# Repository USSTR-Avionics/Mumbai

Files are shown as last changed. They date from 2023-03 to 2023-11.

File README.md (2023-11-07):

`aamchi mumbai!!!`




# Introduction

Welcome to our hardware-based repository, dedicated to providing innovative designs for modular boards that utilize the CANbus interface. At our repository, we strive to bring the benefits of modularity to hardware design, allowing for greater flexibility, scalability, and customization. Our designs are built using the robust and reliable CANbus interface, ensuring efficient communication and seamless integration between modules. Whether you're a hardware enthusiast, a researcher, or an engineer looking to build custom hardware solutions, our repository has something to offer. Our goal is to create a community of like-minded individuals who are passionate about hardware design, and we invite you to join us on this exciting journey. Browse our collection of designs, collaborate with others, and let's push the boundaries of what's possible with modular hardware.

PDB and GPS copied over from: https://github.com/USSTR-Avionics/PDB and https://github.com/USSTR-Avionics/gps-board

RF board based on OpenLST: https://github.com/OpenLST/openlst-hw

## Standard and Unified Connector Kit
Pinout  
10x2 connector

|  | 1 | 2 | 3 | 4 | 5 | 6 | 7 | 8 | 9 | 10 |
|---|---|---|---|---|---|---|---|---|---|---|
| **A** | GND | 3V3 |GND | 3V3 | GND | 5V | GND | 5V | GND | Bus voltage | 
| **B** | GND | CAN high | CAN low | GND | GPIO | GPIO | GPIO | GPIO | GPIO  | GPIO  

(left to right, topview)

[hard to flip header](https://www.digikey.ca/en/products/detail/sullins-connector-solutions/SFH11-PBPC-D10-ST-BK/1990090)

## PCB Dimensions Drawing
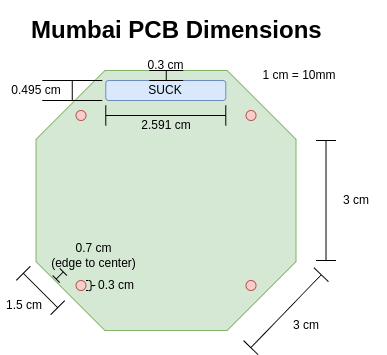
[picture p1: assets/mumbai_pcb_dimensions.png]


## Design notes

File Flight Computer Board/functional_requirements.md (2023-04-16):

# Purposes and Scope

The flight computer should be a general purpose flight computer that allows us to have high performance, modularity,
encapsulation and object oriented design. Provide unparalledled situational awarenedd using edge functions on the
lambda cloud. All instructions and code are encrypted using null key encryption and single source of truth blockchain
technologies to avoid tampering with the data.

# Functional Requirements

## Materials
- microcontroller
    - STM32F205RBT6 
    - debug/ program pins

- attitude sensors
    - accelerometer
    - gyroscope
    - magnetometer
    - barometer

- IO peripherals
    - multi-colour LED arrays
    - buzzer
    - FRAM

- communication
    - CAN transceiver

# Non-functional Requirements

- sensor redundancy
    - accelerometer
    - gyroscope
    - magnetometer
    - barometer

# Assumptions and Dependencies

All of it will work

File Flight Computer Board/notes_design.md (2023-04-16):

- NRST pulled low, reset the uc, contains internal pullup resistor
    - maybe attach an external switch

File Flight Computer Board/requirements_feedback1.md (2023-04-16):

# Materials
- microcontroller
* WHAT MICROCONTROLLER, STM32***, will be decided by Dylan
- MS5611
** REASEARCH DIFFERENT BAROMETERS AND GIVE ME AN ANALYSIS ON WHAT ONE IS BEST, HOW MANY FOR REDUNDANCY
- KX134
** REASEARCH DIFFERENT ACCELEROMETERS AND GIVE ME AN ANALYSIS ON WHAT ONE IS BEST, HOW MANY FOR REDUNDANCY
- BMP280
- MPU6050
** DIFFERENT IMU, AN IMU HAS AN ACCELEROMETER IN IT, 9 AXIS WOULD BE NICE 6 is OK
- indicator LEDs
*SURFACE MOUNT
- buzzer
* GIVE ME A USABLE BUZZER, IT JUST HAS TO WORK
- CAN transceiver
* WILL BE STANDARDIZED BY DYLAN
THE FLIGHT COMPUTER SHALL DO THIS **MUST
THE FLIGHT COMPUTER SHOULD DO THIS *NICE TO HAVE
# Functionality
- get serial monitor output
- transmit and receive CAN messages from all boards on CAN BUS
- GPIO pins for extensibilty (CONNECTORS????!!!!)
- Be programmable from the outside of the rocket, easily accessible
- Shall be able to convert analog sensor values to digital values (instrumention, current/voltage)

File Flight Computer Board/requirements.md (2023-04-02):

# Materials

- microcontroller
- MS5611
- KX134
- BMP280
- MPU6050
- indicator LEDs
- buzzer
- CAN transceiver

# Functionality

- ability to program the microcontroller
- get serial monitor output
- transmit and receive CAN messages
- GPIO pins for extensibilty

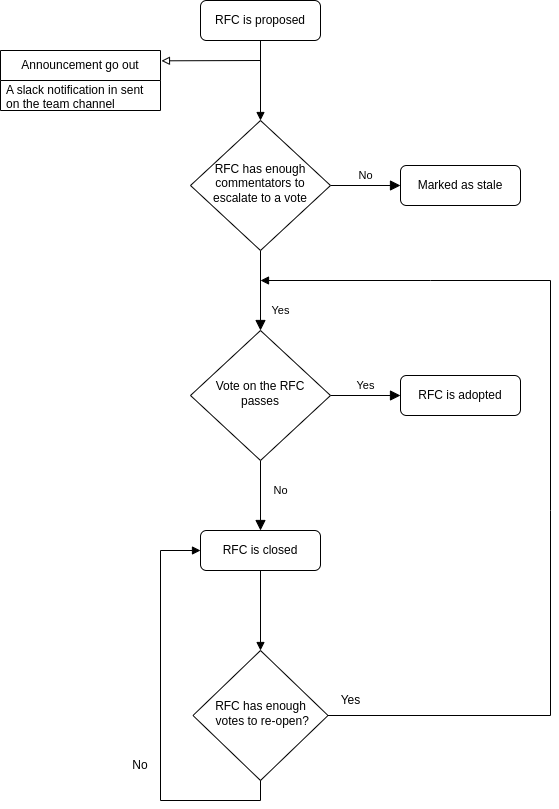
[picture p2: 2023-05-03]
assets/rfc_process_diagram.png

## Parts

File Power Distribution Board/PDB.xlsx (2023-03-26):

Reference | Quantity | Value | Footprint | LCSC Part #
C101 C102 C107 C108 C109 | 5 | 0.1uF | Capacitor_SMD:C_0805_2012Metric_Pad1.18x1.45mm_HandSolder
C103 C104 | 2 | 10uF | Capacitor_SMD:C_0805_2012Metric_Pad1.18x1.45mm_HandSolder
C105 C106 | 2 | 22uF | Capacitor_SMD:C_0805_2012Metric_Pad1.18x1.45mm_HandSolder
C110 | 1 | 4u7 | Capacitor_SMD:C_0805_2012Metric_Pad1.18x1.45mm_HandSolder | C19666
C111 C113 | 2 | 30p | Capacitor_SMD:C_0805_2012Metric_Pad1.18x1.45mm_HandSolder | C1570
C112 C114 C116 C117 C118 | 5 | 100n | Capacitor_SMD:C_0805_2012Metric_Pad1.18x1.45mm_HandSolder | C1525
C115 | 1 | 1u | Capacitor_SMD:C_0805_2012Metric_Pad1.18x1.45mm_HandSolder | C52923
D101 | 1 | SB140 | Diode_THT:D_DO-41_SOD81_P10.16mm_Horizontal
D102 D103 D104 | 3 | LED | LED_SMD:LED_0805_2012Metric_Pad1.15x1.40mm_HandSolder
J101 | 1 | Conn_01x02_Female | Connector_AMASS:AMASS_XT60PW-F_1x02_P7.20mm_Horizontal
J102 | 1 | Conn_01x08_Female | Connector_PinHeader_1.27mm:PinHeader_1x08_P1.27mm_Horizontal
J104 | 1 | Conn_01x06_Female | Connector:Tag-Connect_TC2030-IDC-FP_2x03_P1.27mm_Vertical
JP101 | 1 | SolderJumper_2_Open | Jumper:SolderJumper-2_P1.3mm_Open_Pad1.0x1.5mm
L101 | 1 | 27n | Inductor_SMD:L_0402_1005Metric | C18830
R101 | 1 | 120 | Resistor_SMD:R_0805_2012Metric_Pad1.20x1.40mm_HandSolder
R102 | 1 | 200mR | Resistor_SMD:R_0805_2012Metric_Pad1.20x1.40mm_HandSolder
R103 R104 R105 | 3 | 1k | Resistor_SMD:R_0805_2012Metric_Pad1.20x1.40mm_HandSolder
R106 | 1 | 10k | Resistor_SMD:R_1206_3216Metric_Pad1.30x1.75mm_HandSolder
R107 | 1 | 2k | Resistor_SMD:R_1206_3216Metric_Pad1.30x1.75mm_HandSolder
R108 | 1 | 10k | Resistor_SMD:R_0805_2012Metric_Pad1.20x1.40mm_HandSolder | C25744
U101 | 1 | AZ1084-3.3 | Package_TO_SOT_SMD:TO-252-2
U102 | 1 | MCP2562-H-SN | Package_SO:SOIC-8_3.9x4.9mm_P1.27mm
U103 | 1 | AZ1117-5.0 | Package_TO_SOT_SMD:TO-252-3_TabPin2
U104 | 1 | INA180 | Package_TO_SOT_SMD:SOT-23-5_HandSoldering
U105 | 1 | STM32F103C8T6 | Package_QFP:LQFP-48_7x7mm_P0.5mm | C8734
Y101 | 1 | 8MHz | Crystal:Crystal_SMD_5032-2Pin_5.0x3.2mm | C115962

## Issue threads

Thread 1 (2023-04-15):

Radio Board revA Hardware schematic RFC

ATGr8, 2023-04-15:
Need two Passes to move onto layout as discussed in the design review.
Design files: https://github.com/USSTR-Avionics/Mumbai/tree/master/RF
Let me know if you have further questions

tyrelkostyk, 2023-04-16:
Approved.

Since the majority of these changes are utilizing a somewhat proven open source design, there's not too much to comment on. Be sure to thoroughly test the added components (external memory), and consider investigating what other people have done when making modifications to the firmware/hardware for this design. There will definitely be some trial-and-error when using that external memory, but it shouldn't be too hard. Let me know if you experience significant issues and I can try and lend a hand.

Colton-Breitkreuz, 2023-04-18:
Approved.

Closed 2023-04-18.

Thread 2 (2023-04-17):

RFC 202304162103 - Standardising and Unifying Connector Kits (SUCK)

frroossst, 2023-04-17:
How do our boards communicate with each other and what does the connector looks like

frroossst, 2023-04-17:
So, in essence the SUCK or the Standard Unified Connector Kit would have
5V
3V3
GND
4x CAN wires(no clue how many wires CAN takes)
GPIOS (number to be specified)

ATGr8, 2023-04-17:
Dont need 4 CAN wires, just two wires: CANH and CANL, so just 2

AstroJosh2002, 2023-04-17:
have a common connector for all boards and only connect what you need on each board

frroossst, 2023-04-17:
We might need a separate bus to not bog down the main CANbus line for things like, images from a camera, or something that takes up a lot of bandwidth

dhaussecker, 2023-04-17:
Why can't you use CAN for everything? Connect sensors to a MCU and that MCU goes to CAN BUS

dhaussecker, 2023-04-17:
What type of sensors would connect to these GPIOs? Are these flight critical sensors?

ATGr8, 2023-04-17:
We don't know yet, but we need the flexibility to add non complex boards that can just plug into the GPIOs, adding a MCU for such boards is overkill and add more points of failure.

dhaussecker, 2023-04-17:
Each board will have standard GPIOs so if a sensor needs to be added to the rocket in a certain location in the future, it can be easily done. It is a transportation system between all boards (priority based) using CAN to easily replace and add more sensors

frroossst, 2023-04-17:
finally!!!!

frroossst, 2023-04-17:
PC104 ftw

dhaussecker, 2023-04-17:
All Boards IN THE STACK can use PC104 Connectors, as long as they will meet launch Canada Requirements

dhaussecker, 2023-04-17:
Boards in other sections of the rocket will need something else, determined later

frroossst, 2023-04-17:
you can't just comment things here that we tell you on discord!

dhaussecker, 2023-04-17:
ALL STANDARDS ARE SUBJECT TO DESIGN CHANGES IF DEEMED NECESSARY IN THE FUTURE

AstroJosh2002, 2023-04-17:
I approve the current design

frroossst, 2023-04-17:
approve deez nuts

frroossst, 2023-04-17:
CENSORSHIP!

AstroJosh2002, 2023-04-17:
I can't believe we spent more than 30 mins convincing Dylan why GPIO is a good idea

frroossst, 2023-04-17:
# Pinout
(left to right)

| GND | 3V3 |GND | 3V3 | GND | 5V | GND | 5V | GND | Bus voltage |
|---|---|---|---|---|---|---|---|---|---|
| GND | CAN hi | CAN lo | GND | GPIO | GPIO | GPIO | GPIO | GPIO  | GPIO

10x2 connector

AstroJosh2002, 2023-04-17:
https://www.digikey.com/en/products/detail/samtec-inc/ESQ-105-23-S-D/7090235

ATGr8, 2023-04-17:
https://www.digikey.ca/en/products/detail/sullins-connector-solutions/SFH11-PBPC-D10-ST-BK/1990090
I like this one cause it has a indication of first row so we cant flip it

AstroJosh2002, 2023-04-17:
https://www.mouser.ca/c/connectors/backplane-connectors/pc-104-connectors/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

ATGr8, 2023-04-17:
https://www.digikey.ca/en/products/filter/rectangular-connectors/headers-receptacles-female-sockets/315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
Digikey filter for us

AstroJosh2002, 2023-04-17:
Header dimentions https://suddendocs.samtec.com/prints/esq-1xx-xx-x-x-xxx-xx-x-xx-mkt.pdf

AstroJosh2002, 2023-04-17:
https://www.mouser.ca/ProductDetail/Samtec/ESQ-110-38-G-D?qs=0lQeLiL1qya%252BPHAV3ltgtA%3D%3D

AstroJosh2002, 2023-04-17:
Probably the best one https://www.mouser.ca/ProductDetail/Samtec/ESQ-110-13-G-D?qs=0lQeLiL1qyaTGIi6Og3PNg%3D%3D

Closed 2023-04-17.

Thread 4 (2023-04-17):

Preliminary selection of micro-controllers for the hardware

frroossst, 2023-04-17:
## Micro-controllers
| Micro-controller | Price |Stock | Core | Max Clock (MHz) | Program Memory Size (MB) | Number of IOs | CAN | I2C | SPI | UART | USART | USB |
|:-----|:-----:|:--:|:----------:|:----:|:----------------:|:--------------------:|:--------:|:----:|:----:|:----:|:----:|:--:|
|STM32F405RGT6 |20.04|0| M4 |168|1|51|1|1|1|1|1|1|
|STM32F407IGT6 |25.71|0|M4|168|1|140|1|1|1|1|1|1|
|STM32F412VGT6|20.2|2143|M4|100|1|81|0|0|0|0|0|0|
|STM32F413VGT6 |19.53|941|M4|100|1|81|1|1|1|1|1|1|
|STM32G0B1VET6|13.85|1064|M0+|64|0.5|94|1|1|1|1|1|0|
|STM32G0C1RET6|12.16|604|M0+|64|0.5|60|1|1|1|1|1|1|
|STM32L4R9VGT6 |25.6|879|M4|120|1|77|1|1|1|1|1|1|
|STM32F412RGT6|19.17|1910|M4|100|1|50|1|1|1|1|1|1|
|STM32L476RET6|18.02|18349|M4|80|0.5|51|1|1|1|1|1|1|
|STM32L462RET6|16.28|3830|M4|80|0.5|52|1|1|1|1|1|1|
|STM32L451RET6TR|15.17|6980|M4|80|0.5|52|1|1|1|1|1|1|

## Footer
> 1 means, it supports that, 0 means it doesn't rather than the actual quantity

frroossst, 2023-04-17:
@dhaussecker need your attention!

dhaussecker, 2023-04-17:
Consider Platform-IO capability, and list what supplier you are getting information on the stock. Option 1 looks the best to me based on this at the moment (but the supply chain crisis might be difficult to navigate, there is stock from other suppliers but IDK where you got your stock information from), also considering availability from JLCPCB parts for potential of quick board manufacturing

STM32F405RGT6 | 20.04 | 0 | M4 | 168 | 1 | 51 | 1 | 1 | 1 | 1 | 1 | 1 | PIO | JLC $7.98 (1075 stock)
STM32F407IGT6 | 25.71 | 0 | M4 | 168 | 1 | 140 | 1 | 1 | 1 | 1 | 1 | 1 | PIO JLC  $48.2687 (581 stock)
STM32F412VGT6 | 20.2 | 2143 | M4 | 100 | 1 | 81 | 0 | 0 | 0 | 0 | 0 | 0 |
STM32F413VGT6 | 19.53 | 941 | M4 | 100 | 1 | 81 | 1 | 1 | 1 | 1 | 1 | 1 |
STM32G0B1VET6 | 13.85 | 1064 | M0+ | 64 | 0.5 | 94 | 1 | 1 | 1 | 1 | 1 | 0 | NOPIO
STM32G0C1RET6 | 12.16 | 604 | M0+ | 64 | 0.5 | 60 | 1 | 1 | 1 | 1 | 1 | 1
STM32L4R9VGT6 | 25.6 | 879 | M4 | 120 | 1 | 77 | 1 | 1 | 1 | 1 | 1 | 1
STM32F412RGT6 | 19.17 | 1910 | M4 | 100 | 1 | 50 | 1 | 1 | 1 | 1 | 1 | 1 | PIO JLC 13.8318 (86 stock)
STM32L476RET6 | 18.02 | 18349 | M4 | 80 | 0.5 | 51 | 1 | 1 | 1 | 1 | 1 | 1
STM32L462RET6 | 16.28 | 3830 | M4 | 80 | 0.5 | 52 | 1 | 1 | 1 | 1 | 1 | 1
STM32L451RET6TR | 15.17 | 6980 | M4 | 80 | 0.5 | 52 | 1 | 1 | 1 | 1 | 1 | 1

frroossst, 2023-04-17:
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

Stock information is from mouser.ca and digikey.ca. (mostly mouser)

Also, not to be THAT guy, but PlatformIO compatibility just needs to be thrown down the drain, at least from my perspective (writing firmware) I won't be able to use pio, I have to use the STM_IDE. Most of these are however compatible with pio. But we wouldn't know until we try it out. In essence, if the CPU and architecture are supported, so should a specific board be.

ATGr8, 2023-04-18:
I second not worrying about PIO compatibility, STMCube IDE gives access to a lot more natively

ATGr8, 2023-04-18:
Another thing to consider would be the package, you don't wanna get QFN or BGAs because those would be painful to solder

frroossst, 2023-04-18:
I mainly went with a LQM package

ATGr8, 2023-04-18:
As long as the pins aren't _under_ the chip its fine.

For the UART and USART: are they on different pins or is the UART able to add a clock to make USART?

dhaussecker, 2023-04-18:
Only 3 microcontrollers have platform io capability from what I can tell. It was a group decision 2 weeks ago in the avionics meeting that the people programming the software want the capability to program these microcontrollers using platform io as it takes considerably less time to program it there. PIO will still be taken into consideration

frroossst, 2023-04-18:
Right, but the team that decided things 2 weeks ago, is not programming the firmware. Also, it is simply impractical to do it with PlatformIO

Also to answer Atharva's question.
> The STM32L4Rxxx devices have three embedded universal synchronous receiver
transmitters (USART1, USART2 and USART3) and two universal asynchronous receiver
transmitters (UART4, UART5)
I think you just attach an external clock

ATGr8, 2023-04-18:
Has the team tried out STM Cube IDE? I don't think taking PIO compatibility as a primary reason for making this decision is a good idea, I wouldn't sacrifice performance for PIO compatibility. However if two have same performance and once supports PIO, we should choose the one with PIO compatibility

frroossst, 2023-04-18:
PIO is 100% better than Arduino, and I hate, HATE, H A T E using proprietary IDEs, but the STM IDE is just far superior for the STM platform. We should choose a micro-controller and then figure our pio, cause regardless it will still work with STM IDE

frroossst, 2023-04-18:
On the topic of the micro-controller, I am leaning towards this [one](https://www.mouser.ca/ProductDetail/STMicroelectronics/STM32L4R9VGT6?qs=wd5RIQLrsJi9fM%2FlO6Dzzw%3D%3D)

Although I would like one with multiple CAN transceivers

ATGr8, 2023-04-18:
@dhaussecker @frroossst
I think it would be a fair sacrifice as considering PIO compatibility as a secondary reason to choose the MCU.

Afterall no one on the team is writing the firmware because there is no STM firmware to write. PIO compatibility would be a nice to have  and would lower the barrier to entry.

ATGr8, 2023-04-18:
> On the topic of the micro-controller, I am leaning towards this [one](https://www.mouser.ca/ProductDetail/STMicroelectronics/STM32L4R9VGT6?qs=wd5RIQLrsJi9fM%2FlO6Dzzw%3D%3D)

Although I would like one with multiple CAN transceivers
It looks like 25 bucks a pop, don't think that's very economical

dhaussecker, 2023-04-18:
I don't think that one is the best decision at all

frroossst, 2023-04-18:
I also love this [one](https://www.mouser.ca/ProductDetail/STMicroelectronics/STM32F205RBT6?qs=ZjM2s42DDyaIgcG0HgMB8w%3D%3D) but, it's on order.

dhaussecker, 2023-04-18:
PIO capability will be a main priority as it reduces the gap of knowledge needed for members to begin programming. Also, makes things way simpler to program. I don't know if either of you have tried programming an STM32 with PIO but I have, it is simple cause you can just import the Arduino library and utilize all extensive libraries that are in that ecosystem. STM32 Cube IDE programming is a secondary objective IMO

ATGr8, 2023-04-18:
Have you tried programming the STM32 Cube IDE? To wirte low level firmware?

ATGr8, 2023-04-18:
Things like assigning pin functions, setting registers is very easy in the Cube IDE cause its all natively built for a particular chip. Doing the same thing on PIO wont work as well and will be difficult. Plus why are we importing Arduino libraries here to write the drivers/firmware?

dhaussecker, 2023-04-18:
But we don't need to be writing low level firmware for this in the first place?! Make things as simple as they can  be

ATGr8, 2023-04-18:
Yes we do. Our boards require us to write low level firmware. Our boards will be bare metal.

frroossst, 2023-04-18:
ummm.....

dhaussecker, 2023-04-18:
They do not have to be bare metal, we will be wasting time writing software when we could be doing other things if we had all the libraries that are provided with PlatformIO-compatible STM32s through the Arduino ecosystem. We will have a lot of tasks to do this year and teaching new first years how to program low level firmware in STM32 IDE is not feasible IMO, especially when we struggled getting everyone to code in PlatformIO at times during this year. For more experienced programmers, sure! Why not use STM32 CubeIDE? It gives you a lot more experience writing low level firmware. But we also need to keep the option for new students who don't know anything about programming, to reduce the learning gap and to keep things as simple as possible.

frroossst, 2023-04-18:
a. If we're not doing bare metal, what are we doing?
b. We will be using the STM32 IDE regardless, as it provided a HAL, pinout and much more. so it's useful for design purposes
c. The first years will not write firmware, by firmware we mean, can bus drivers and stuff. You do not want to mess with dependencies when doing embedded stuff, or heck even C/C++ stuff as they have no good dependency managers
d. We cannot use the two platforms (no pun intended) interchangeably because they operate on different linker scripts
e. If we wanna reduce the learning gap, that the whole stm32 thing might be a bad idea, as they are fundamentally more advanced when compared to something like a Teensy or an Arduino-alternative

ATGr8, 2023-04-18:
I see your point here, but STM 32 Cube is not a steep learning curve and you don't have to write low level firmware in STM32Cube, it could be as high level as PIO.
STM32Cube has more libraries supporting STM32 than PIO, it has the abilities to detect hardware faults.
I'm not against using PIO, but I don't think its justified to use its compatibility as one of the main deciding factors.
Members can also just use VSCode and only click build on Cube IDE if needed, we could also figure out a way to integrate those two.

frroossst, 2023-04-18:
Not to mention, with STM32 you can have hardware breakpoints for days!

dhaussecker, 2023-04-18:
The team as a whole decided that platformIO is the best way to go for now, without formal agreement that STM32 CubeIDE is best in the future I need the majority of the people who will be doing software to agree. In order to determine the feasibility of platformio over stm32 or vice versa we need to do some more programming in both first and make a convincing argument that one is better and convince the majority to accept the argument. Until then I am putting a restriction that the microcontroller needs to be able to be programmed using PlatformIO. @frroossst  had the same concern when I wanted to switch to STM32CubeIDE previously and I followed that suggestion as that is what the team decided. So convince the entire team first who will ultimately end up programming this as well, if you do, I'm good with it. In the meantime, it shouldn't be that difficult to select one that meets all your requirements, the STM32F405RGT6 is $7.98 and is available from LCSC electronics

frroossst, 2023-04-18:
Technically, majority of the people who do software is me. I have more commits on MiniRocket repo than everyone combined (including an effin' linting bot), and since they are commits, Dylan can't make an argument that I just copy pasted the entire code base, cause that's not how commits work. So, I agree we should use STM, therefore, your entire software team is in agreement.

No offense ofc.

frroossst, 2023-04-18:
Also, we don't need to get the whole team's approval on everything. Direct democracy is a very bad thing for an engineering project, We need someone to make decisions that might be unpopular, I am not saying disregard the team, cause I am part of the team lol, but this RFC is a way of getting the team's feedback. If you keep this open for a week or two and no team members are active on here, and then by de facto they have lost the privilege to have their say. So, keep this open for 2 week(s) or so, but, if there are no oppositions here then the decision is made.

dhaussecker, 2023-04-18:
Dylan, Atharva, and Adhyan decided STM32F405RGT6 was the final decision

Closed 2023-04-19.

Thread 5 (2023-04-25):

RFC 202304242108: We do *not* need a memory board

frroossst, 2023-04-25:
- adding a memory board or data logger can create unnecessary redundancy and add complexity to the system.
-  it would need to be programmed to collect data from the other boards, which can create a risk of data loss or communication errors.
- the added weight and size of the memory board or data logger can affect the overall performance of the rocket and potentially impact the flight trajectory.
- centralised board introduces a single point of failure
- If each board logs its own data, it can be done at a higher frequency or a different tick rate than a centralized memory logger. This can provide more accurate and detailed information about the performance of each component, which can be useful for troubleshooting and analysis.
- With each board logging its own data, it can be easier to identify which specific component or subsystem caused any issues during flight. This can help to pinpoint problems and make improvements for future launches.
- With each board logging its own data, it can be easier to identify and isolate any faults or issues that occur during flight. This can help to improve fault tolerance and make the rocket more resilient to future failures.
- With each board logging its own data, the data can be easily transferred to a computer for analysis without the need for a centralized memory logger. This can simplify the data transfer process and reduce the risk of data loss or corruption during transfer.
- Each board can be programmed to log specific data points that are relevant to its function, rather than having to log all data on a centralized logger. This can help to optimize the use of storage space and improve the accuracy of the data collected.
- With each board logging its own data, it can be possible to perform real-time data analysis during flight. This can allow for immediate adjustments to be made if any issues are detected, improving the overall performance and safety of the rocket.
- If each board logs its own data, it can be easier to swap out individual components or subsystems without affecting the data collection process. This can help to improve the modularity of the rocket and make it easier to upgrade or repair.

> Disclaimer: This post is not associated with the Rust Foundation :tm: and powered by chatGPT

<!-- probot = {"36936151":{"who":"frroossst","what":"about RFC vote","when":"2023-05-02T09:00:00.000Z"}} -->

ATGr8, 2023-04-25:
I agree, we do not need a data logger board, it adds complexity that is not necessary and we can just log data from the board the data is coming from in the first place

AstroJosh2002, 2023-04-25:
I'm also in agreement that having more points of failure in the system will cause more problems not only in flight but also during testing. If you have the option to put storage space on the flight computer, why have a seperate board for logging the data to when you can put a larger amount of storage space on your flight computer. Also having more information flowing on the CAN Bus lines has the risk of slowing it down, this can be dangerous when the flight computer needs to make timely decisions and if that's delayed it can put people's safety at risk

frroossst, 2023-04-25:
Here are a few ways we can store data if using a central data logger, the important assumption being data comes in at different tick rates.

1. Have a different chip for every different data type
    - Inefficient to scale
    - Cannot easily change the schema

2. Attach a tagging field
    - Wasting space (would need at least two more bytes, one for the data type being stored and one for how many bytes follow that

3. Hashing
    - Impossible to create a hash function that would have zero collisions

4. Serialising a data chunk
    - Would waste space if a data element is ticked in extremely fast

5. Round Robin Circular Buffer data chunk serialisation
    - Probably the best solution
    - Very space efficient (stores the same amount as the actual data being stored)
    - Difficult to implement, still would waste some space overall

---
This however still does not solve my further hesitation, if any given board does not have any onboard memory chips to store data then while debugging I'll always need to have two boards connected over CAN when debugging, if any given board does indeed have some memory chips on board for quick storage and access then why not increase that storage space and eliminate the memory board altogether?

frroossst, 2023-04-28:
/remind 4 days

frroossst, 2023-04-28:
/remind me about RFC vote in 4 days

dhaussecker, 2023-04-30:
As discussed previously, you are free to implement data logging functionality on the flight computer. we are implementing a data logger board right now for the case that you fail in successfully implementing it on the flight computer which I have deemed it has a high risk at this point with all the other priorities of this board, and time for programming. Prove me wrong 😉 I think a data logger board  would be the perfect “black box” of the system just like airplanes have used for the purposes of redundancy.

frroossst, 2023-05-01:
Again, the central problem with a data logger is an implementation scheme that is memory efficient with all that data coming in at different rates in a non-specific order.

If your data logger fails then you loose 100% of the data, it adds one more board, one more microcontroller to program, one more point of failure. If data logging is handled by each board then we can in theory loose multiple boards while still being able to salvage back some data. A centralised data-logger adds one more layer of complexity.

As @ATGr8 pointed out before, it needs to be a closed loop system, if your data logger shits the bed, then the flight computer cannot get back data.

Also, why would we fail to implement a datalogger on the flight computer? We literally did it on the MiniRocket.

Sidenote: there is no point of an RFC system, if decisions are made unilaterally,

dhaussecker, 2023-05-01:
I believe you are confusing points of failure with redundancies. This is a redundancy which launch Canada wants for all essential systems. I agree with having a chip on every board for the purpose of redundancy

frroossst, 2023-05-01:
Show me where Launch Canada says, we need to have redundancy for data logging

Ukrainianvengeance, 2023-05-02:
How would the control system get all of the flight data? and would we need separate ground stations for each PCB?

frroossst, 2023-05-02:
What do you mean by control system? The flight computer? or the Ground Station?

If you are talking about the flight computer then CANbus? if the ground station then just CANbus and then the radio board handles it?

Can you elaborate a little more on your question?

Ukrainianvengeance, 2023-05-02:
I think I misunderstood yesterday, the data logger would just store the data not process and use the data for flight, right?

frroossst, 2023-05-02:
Yes, it would just be storing the data. Do you have any concerns or questions about it?

Ukrainianvengeance, 2023-05-02:
I no longer have concerns about it and agree with your conclusion as to not needing a central data logger

bristine02, 2023-05-02:
One of our most important goals is modularity and I think having a centralized data logger would make it a little more difficult and messy to add new boards to our system. I think  having each board do its own data collection will help a lot in making our boards modular. It'll also be a lot simpler to test and debug. Also if we decided to swap a board or change stuff on it, we won't need to also make changes to a data logger ( which might affect other boards).

frroossst, 2023-05-03:
Eligible voters: @ATGr8 @AstroJosh2002 @bristine02 @dhaussecker @frroossst @Ukrainianvengeance

:+1: if you are **in support** of the RFC, i.e. there **shouldn't** be a centralised memory logger on board
:-1: if you are **in opposition** of the RFC i.e. there **should** be a centralised memory logger on board

_votes are closed, when all the eligible voters have voted or it is midnight!_

frroossst, 2023-05-03:
This RFC officially passes, with 6 votes in favour and 0 against.

For the time being we will not have a separate memory board on the rocket, this RFC **cannot be reopened**, if a discussion needs to be had on an adjacent topic, mention this RFC, but you have to open a new RFC.

Thank you all for participating!

Closed 2023-05-03.

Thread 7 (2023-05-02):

RFC 202305020937: Impl continuous fuzzing

frroossst, 2023-05-02:
# Abstract
Fuzz testing find bugs, faster, better, and with less effort than writing regular tests, allowing us to focus more of our time on writing code, architecture rather than correctness of the code. This was an active RFC on `USSTR-Avionics/MiniRocket`  but it was too late in its life cycle to do this. Ideally, this would be handled by a github action automatically to find and report bugs. Or it can live on the Esterhazy server.

# Problem(s)
Program robustness, memory safety, correctness, undefined behaviour.

# Solution
Use clang's libfuzz, or write our own fuzz library

# Difficulties and Risks
Even after months of looking into it, I still have very little idea on how to write my own fuzzer.

# Estimated costs and timelines
Should write our own fuzzer in about a month or so, with all the features we want, or impl a fuzzer in a week or so. Saves a lot of cost in the long term.

# Proof of concept
Haven't implemented one yet

# References
https://owasp.org/www-community/Fuzzing
https://releases.llvm.org/9.0.0/docs/LibFuzzer.html
https://www.code-intelligence.com/blog/secure-coding-cpp-using-fuzzing
https://github.com/google/honggfuzz
https://github.com/CodeIntelligenceTesting/cifuzz

<!-- probot = {"36936151":{"who":"fuzz","what":"test RFC","when":"2023-05-16T09:00:00.000Z"}} -->

frroossst, 2023-05-02:
This is a complex topic that requires in depth discussions, so I will leave this open for two weeks.

/remind fuzz test RFC in 2 weeks

dhaussecker, 2023-05-03:
Prime example of: “Research done on student rocket projects shows that time and time again, students tend to overcomplicate certain aspects, rather than focusing on the simplest solution that can be effective.”

This is a clear example of this in my opinion, please focus on the simple stuff of implementing all the boards we already have planned and the software for those as that is the simplest thing we can do at this point

dhaussecker, 2023-05-03:
Just because it sounds cool doesn’t mean it is something we need at this point. Reminder: 4 month timeline for all boards and code to be done. Best case scenario this would get done in 2 months,

frroossst, 2023-05-03:
- What research? Source?
- The reasoning is mentioned in the RFC, nowhere is the word "cool" mentioned
- What is your basis for arriving at the conclusion that implementing continuous fuzzing would take 2 months? I LITERALLY linked a reference to a fuzzing library for C++, that you can use right  now
- This in the long term ensures more robust and secure embedded code is written, it **might be** worthwhile to at least have a discussion on it to prevent bugs like the FRAM bug we had!

dhaussecker, 2023-05-03:
- Multiple papers from student project cit this as the most significant issue faced in student projects. For example: https://www.hyrumwright.org/papers/avionics.pdf
- The goal with everything we are doing is asking one simple question: is it absolutely essential for a rocket? Meaning it helps us meet one of the 3 requirements required for avionics (command, control, data acquisition). Remember timelines are quick, we only have a few hours a week committed at this point, any time we can get to make sure our rocket simply works is time we need
- “Should write our own fuzzer in about a month or so”, multiply that timeline by 2 since it will ALWAYS take longer than you think and you get 2 months. If it takes a couple of hours for you to implement an already made library, and develop some documentation on how it works/ how to use it / why is it useful, then I’m for it. But I need to see a valid justification that it will only take a few hours
- if you write good code, get it reviewed properly, and test it,  you shouldn’t have bugs

frroossst, 2023-05-03:
- I haven't dived into the paper yet, but I'll take your word for it now
- It helps the rocket be safe? Since, there is no RTOS, a bug or crash is catastrophic as your engine task stops being executed? What happens on a seg fault? What happens if enough memory can't be allocated? What happens when static variables are mutated improperly? All these operations are inherently even more so an an embedded system
- We should write our own fuzzer eventually, but the goal should be to implement fuzzing in the first place, the crux of the RFC is fuzzing not, implementation of fuzzing. I'm open to any fuzzing lib as long as it serves its purpose and fulfills our needs

ATGr8, 2023-05-05:
Is there a fuzzer that already exists that we can just use?
I like this idea but I don't wanna take away too much time from writing Mumbai software/firmware, could still be convinced that writing our own fuzzer is better for long term but I don't understand it enough to appreciate it.

frroossst, 2023-05-05:
[A gentle introduction to fuzzing C++ code](https://jefftrull.github.io/c++/clang/llvm/fuzzing/sanitizer/2015/11/27/fuzzing-with-sanitizers.html)

I have been saying this for a long time, "If you are smart enough to write tests that catch all the bugs that might arise, aren't you smart enough to write code, without those bugs?" that's why Test Driven Development doesn't work unless you are building something hyper-testable most likely a CLI utililty or a parser.

Writing system tests for a system means emulating the environment around it, which is ridiculously difficult. So, fuzzing just means, you are rawdogging you functions with inputs of all kinds such that you find the bug easily. This is what I've been calling "chaotic testing" for a long time,, just write code, and test it as a full system, something crashes go back and fix.

At work, we've found some very nasty RegEx bugs by just fuzzing. But we all know you should never use RegEx, so that's our bad I guess haha

Closed 2023-05-20.

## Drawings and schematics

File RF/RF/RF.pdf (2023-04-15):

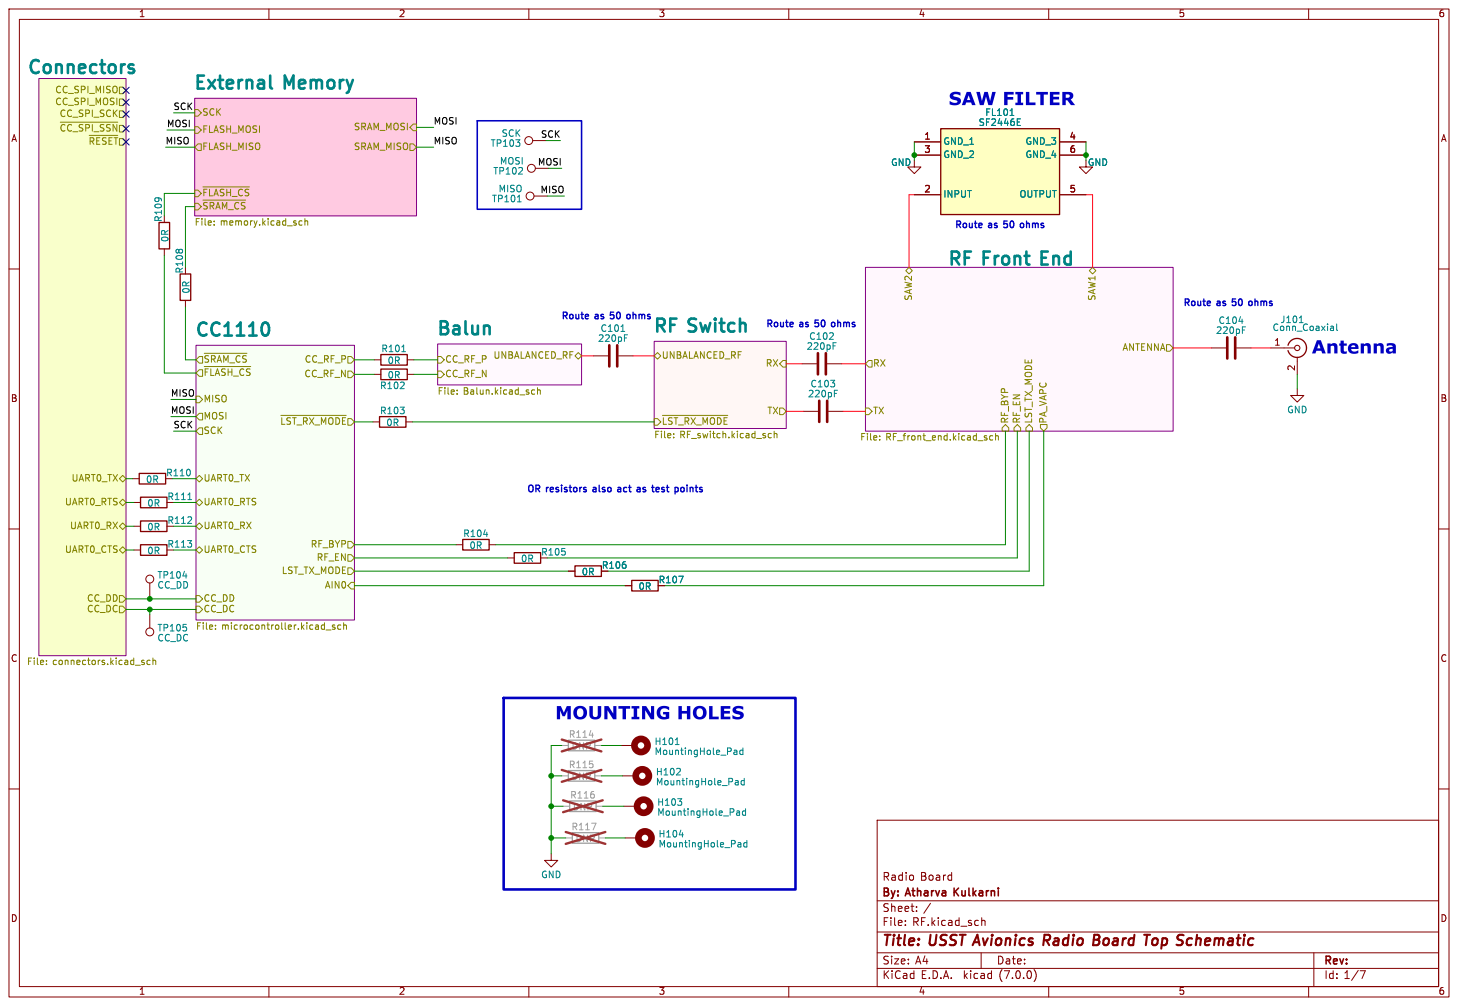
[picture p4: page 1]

Id: 1/7 Title: USST Avionics Radio Board Top Schematic

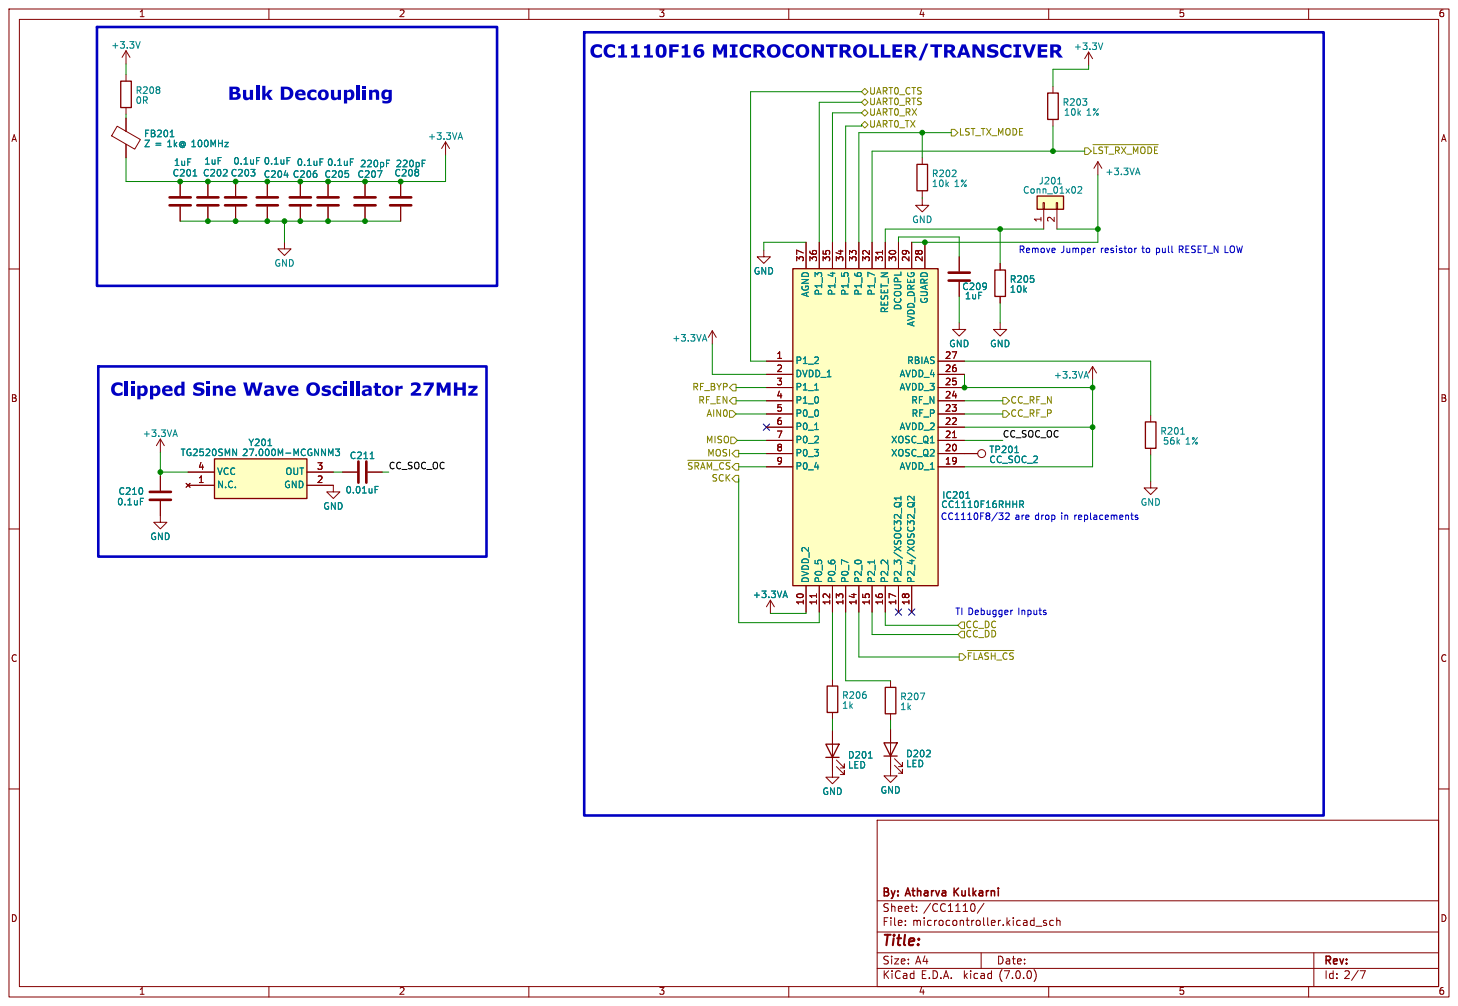
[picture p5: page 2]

Remove Jumper resistor to pull RESET_N LOW

Clipped Sine Wave Oscillator 27MHz

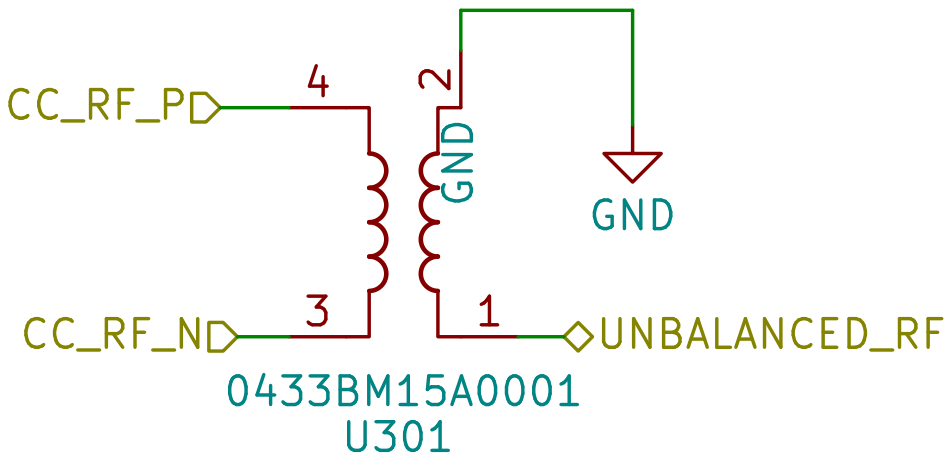
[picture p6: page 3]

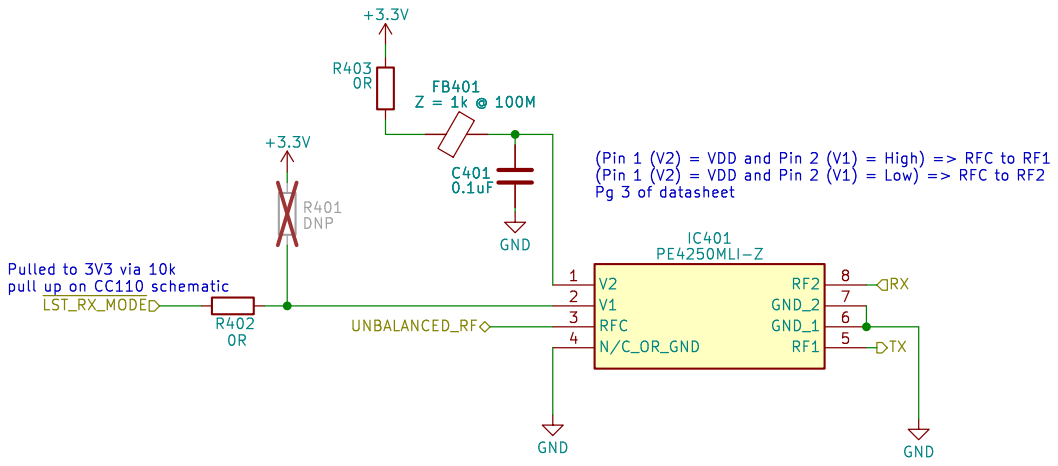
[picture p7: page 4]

(Pin 1 (V2) = VDD and Pin 2 (V1) = Low) => RFC to RF2 Pg 3 of datasheet FB401 Z = 1k @ 100M

(Pin 1 (V2) = VDD and Pin 2 (V1) = High) => RFC to RF1

TX UNBALANCED_RF Pulled to 3V3 via 10k pull up on CC110 schematic

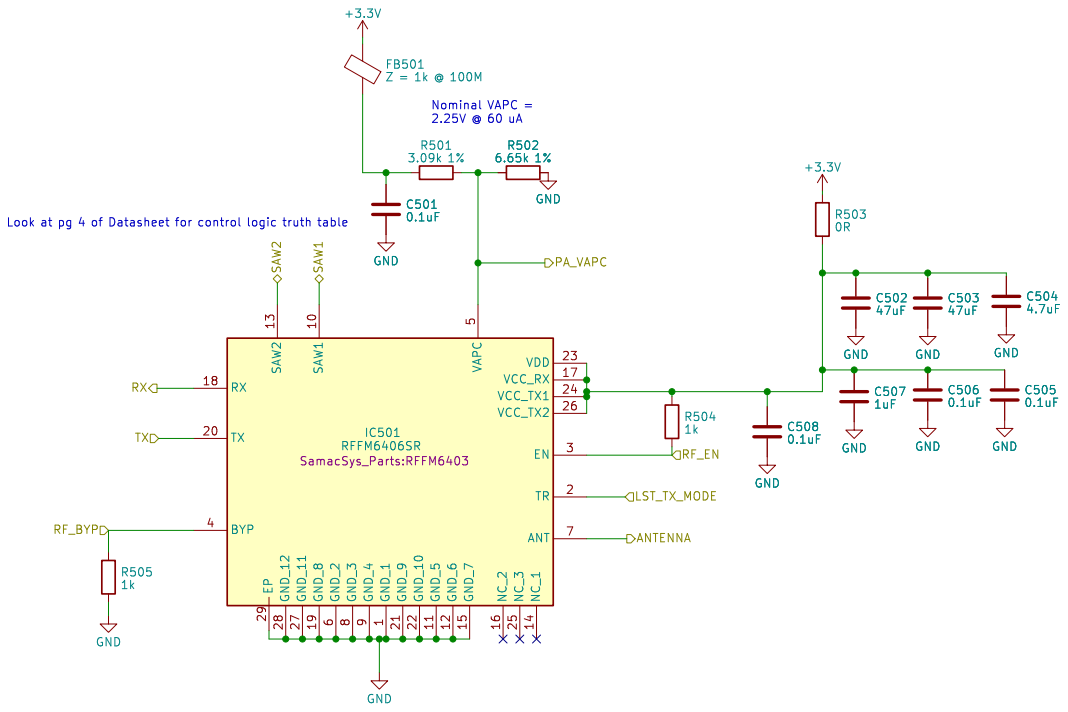
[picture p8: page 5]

1 SAW1 10 GND_5 11 GND_6 12 SAW2 13 NC_1 14 GND_7 15 NC_2 16 VCC_RX 17 RX 18 GND_8 19 TR 2 TX 20 GND_9 21 GND_10 22 VDD 23 VCC_TX1 24 NC_3 25 VCC_TX2 26 GND_11 27 GND_12 28 EP 29 EN 3 BYP 4 VAPC

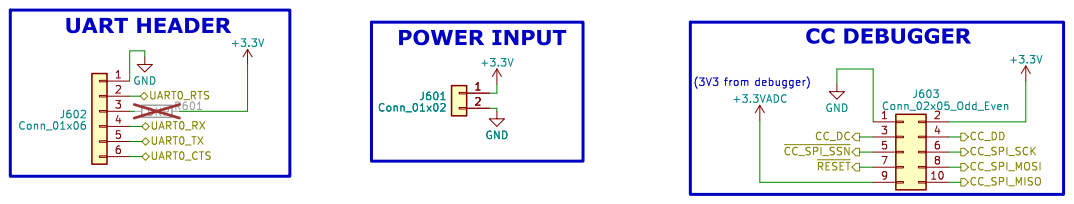
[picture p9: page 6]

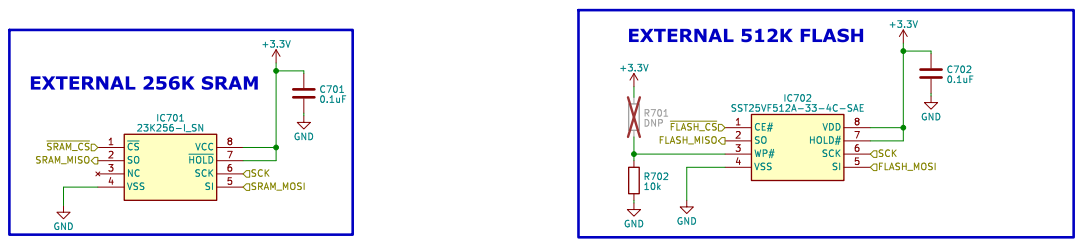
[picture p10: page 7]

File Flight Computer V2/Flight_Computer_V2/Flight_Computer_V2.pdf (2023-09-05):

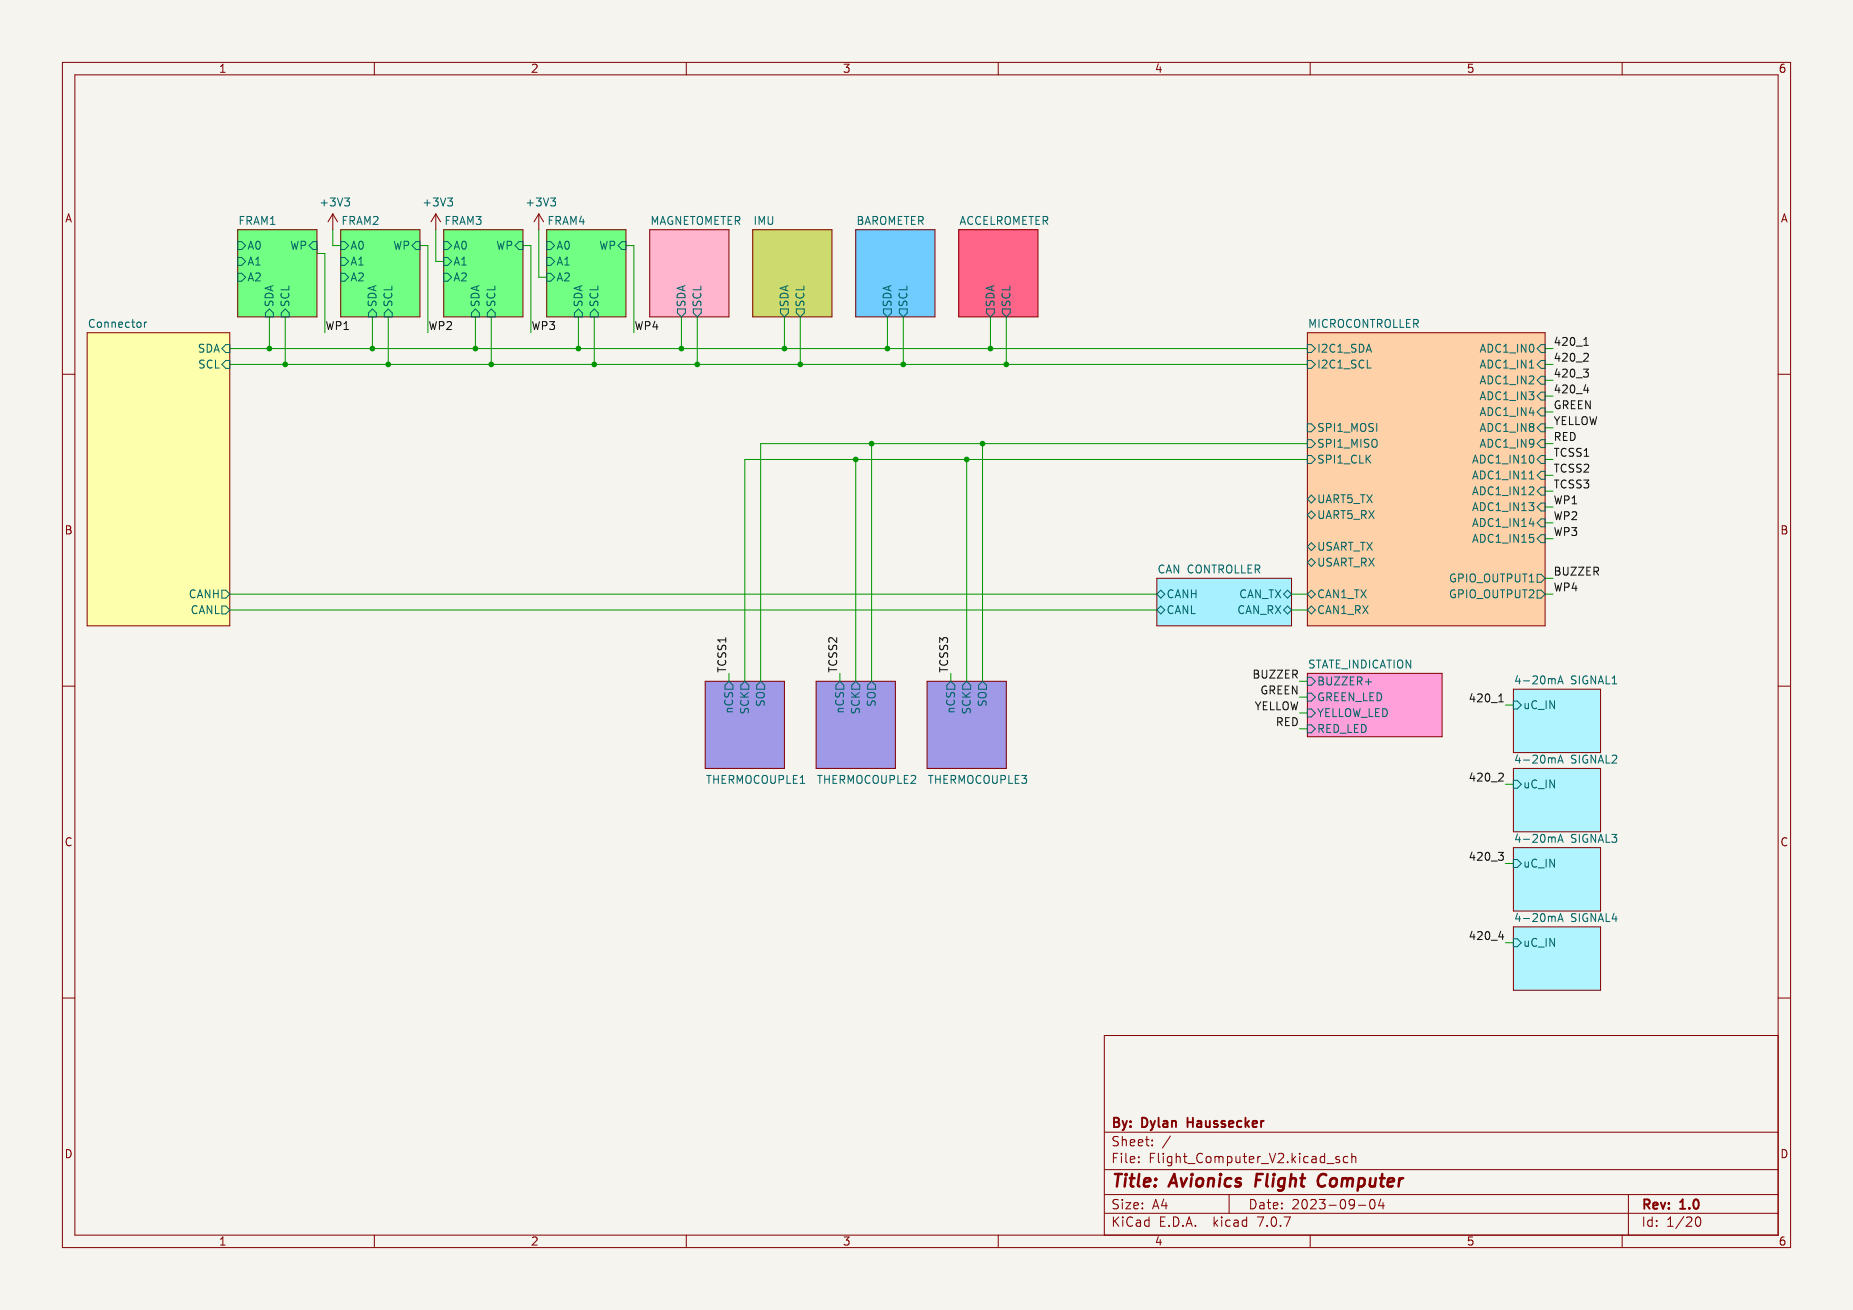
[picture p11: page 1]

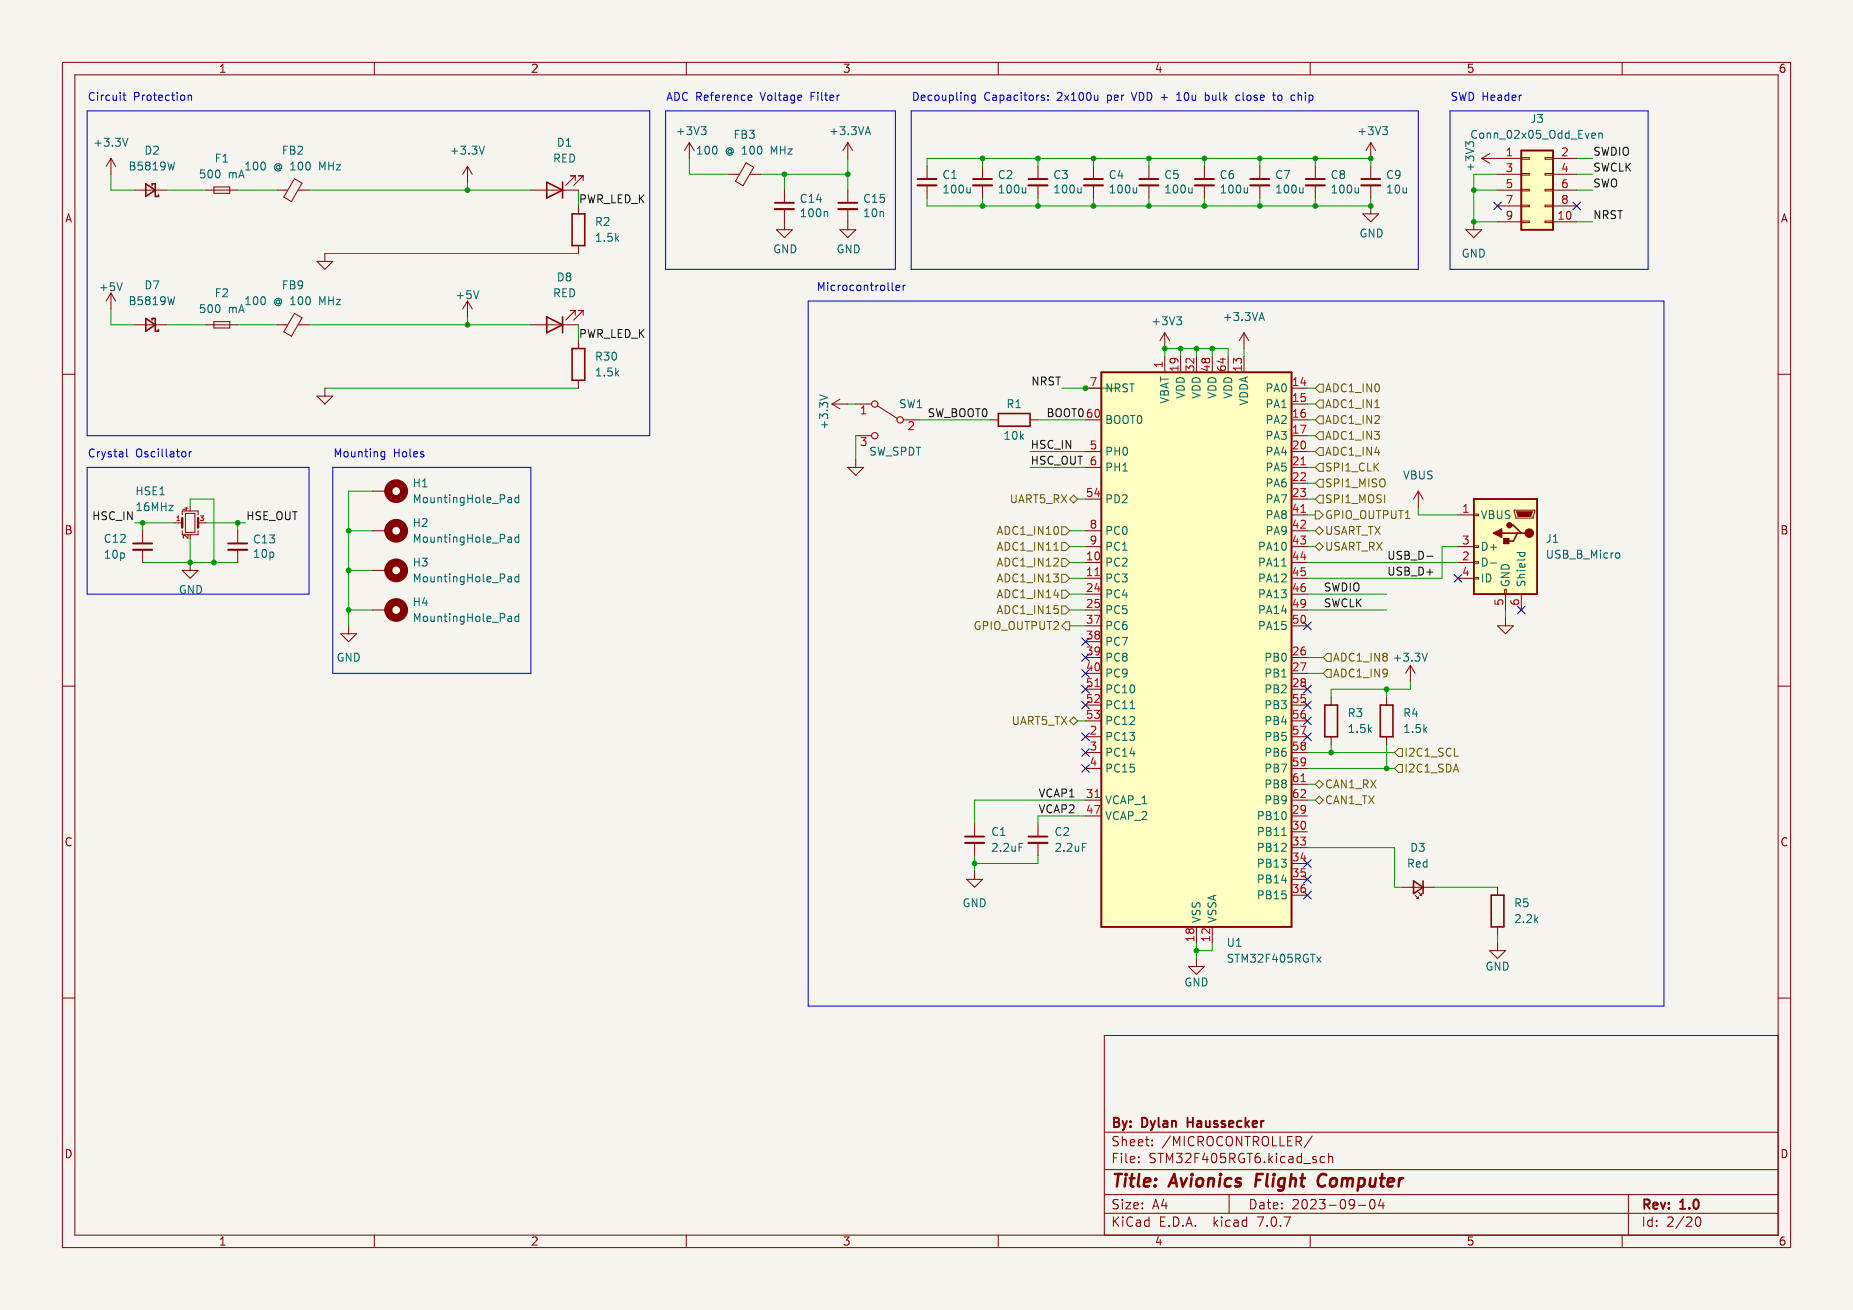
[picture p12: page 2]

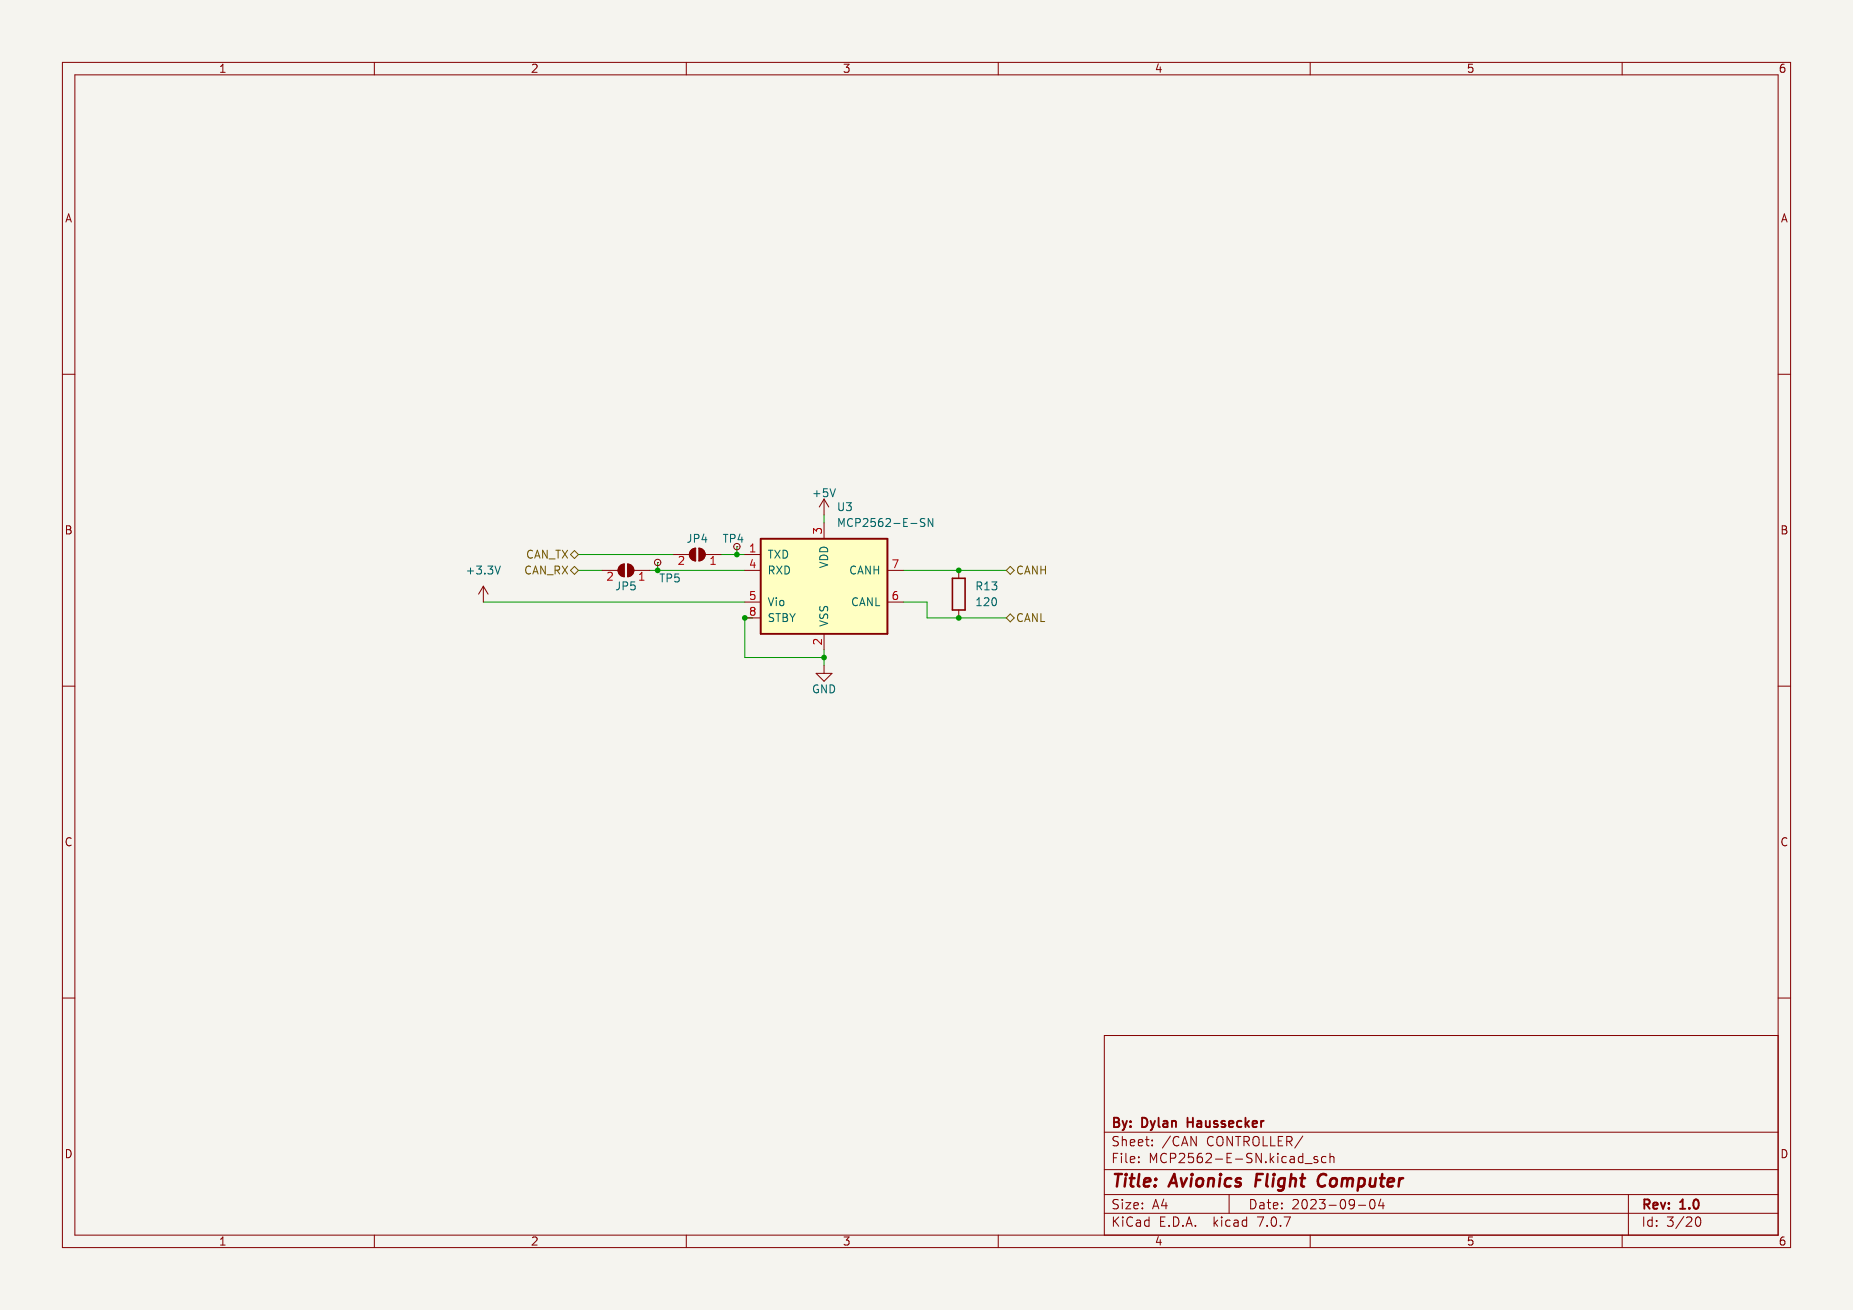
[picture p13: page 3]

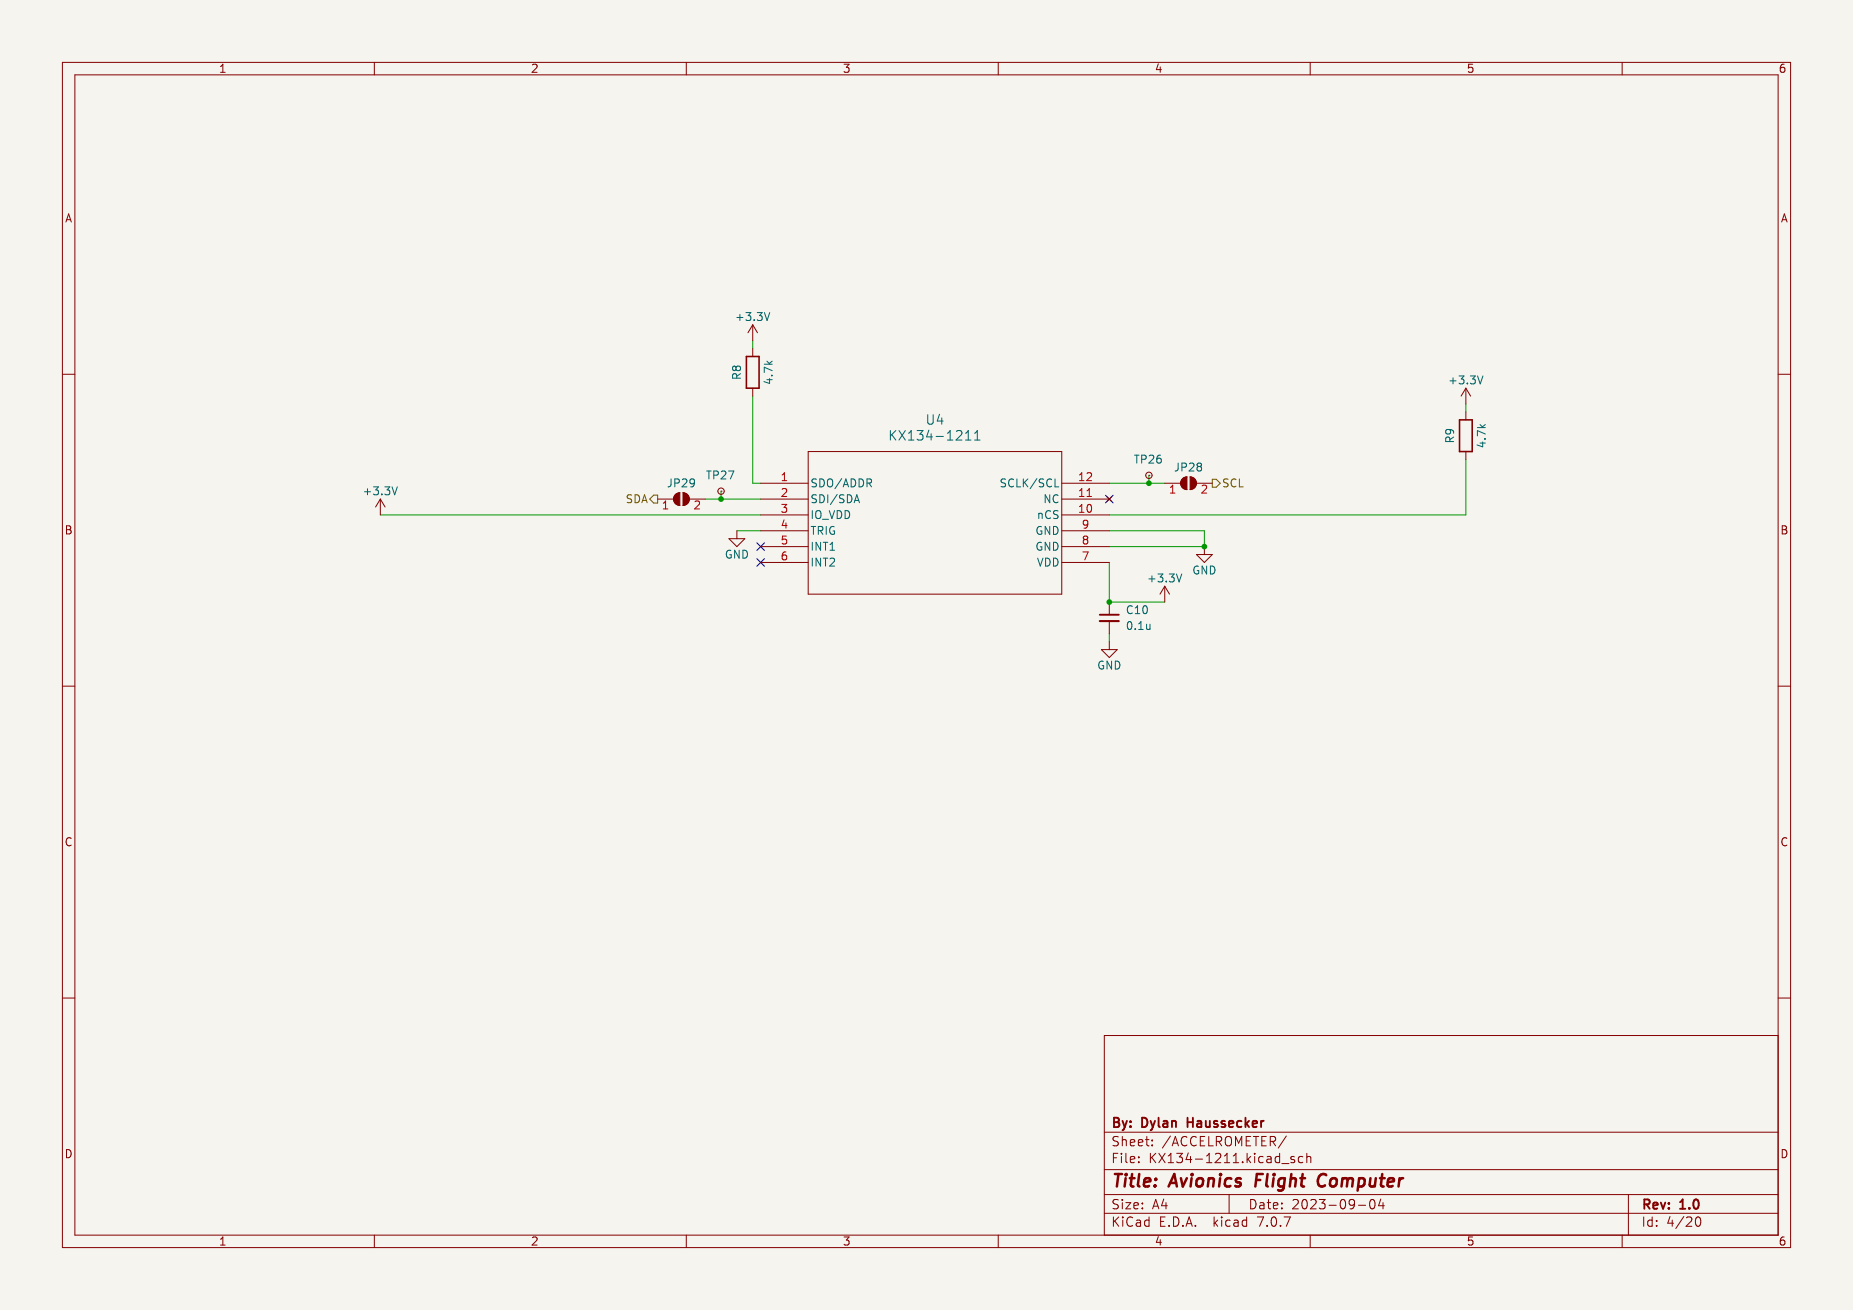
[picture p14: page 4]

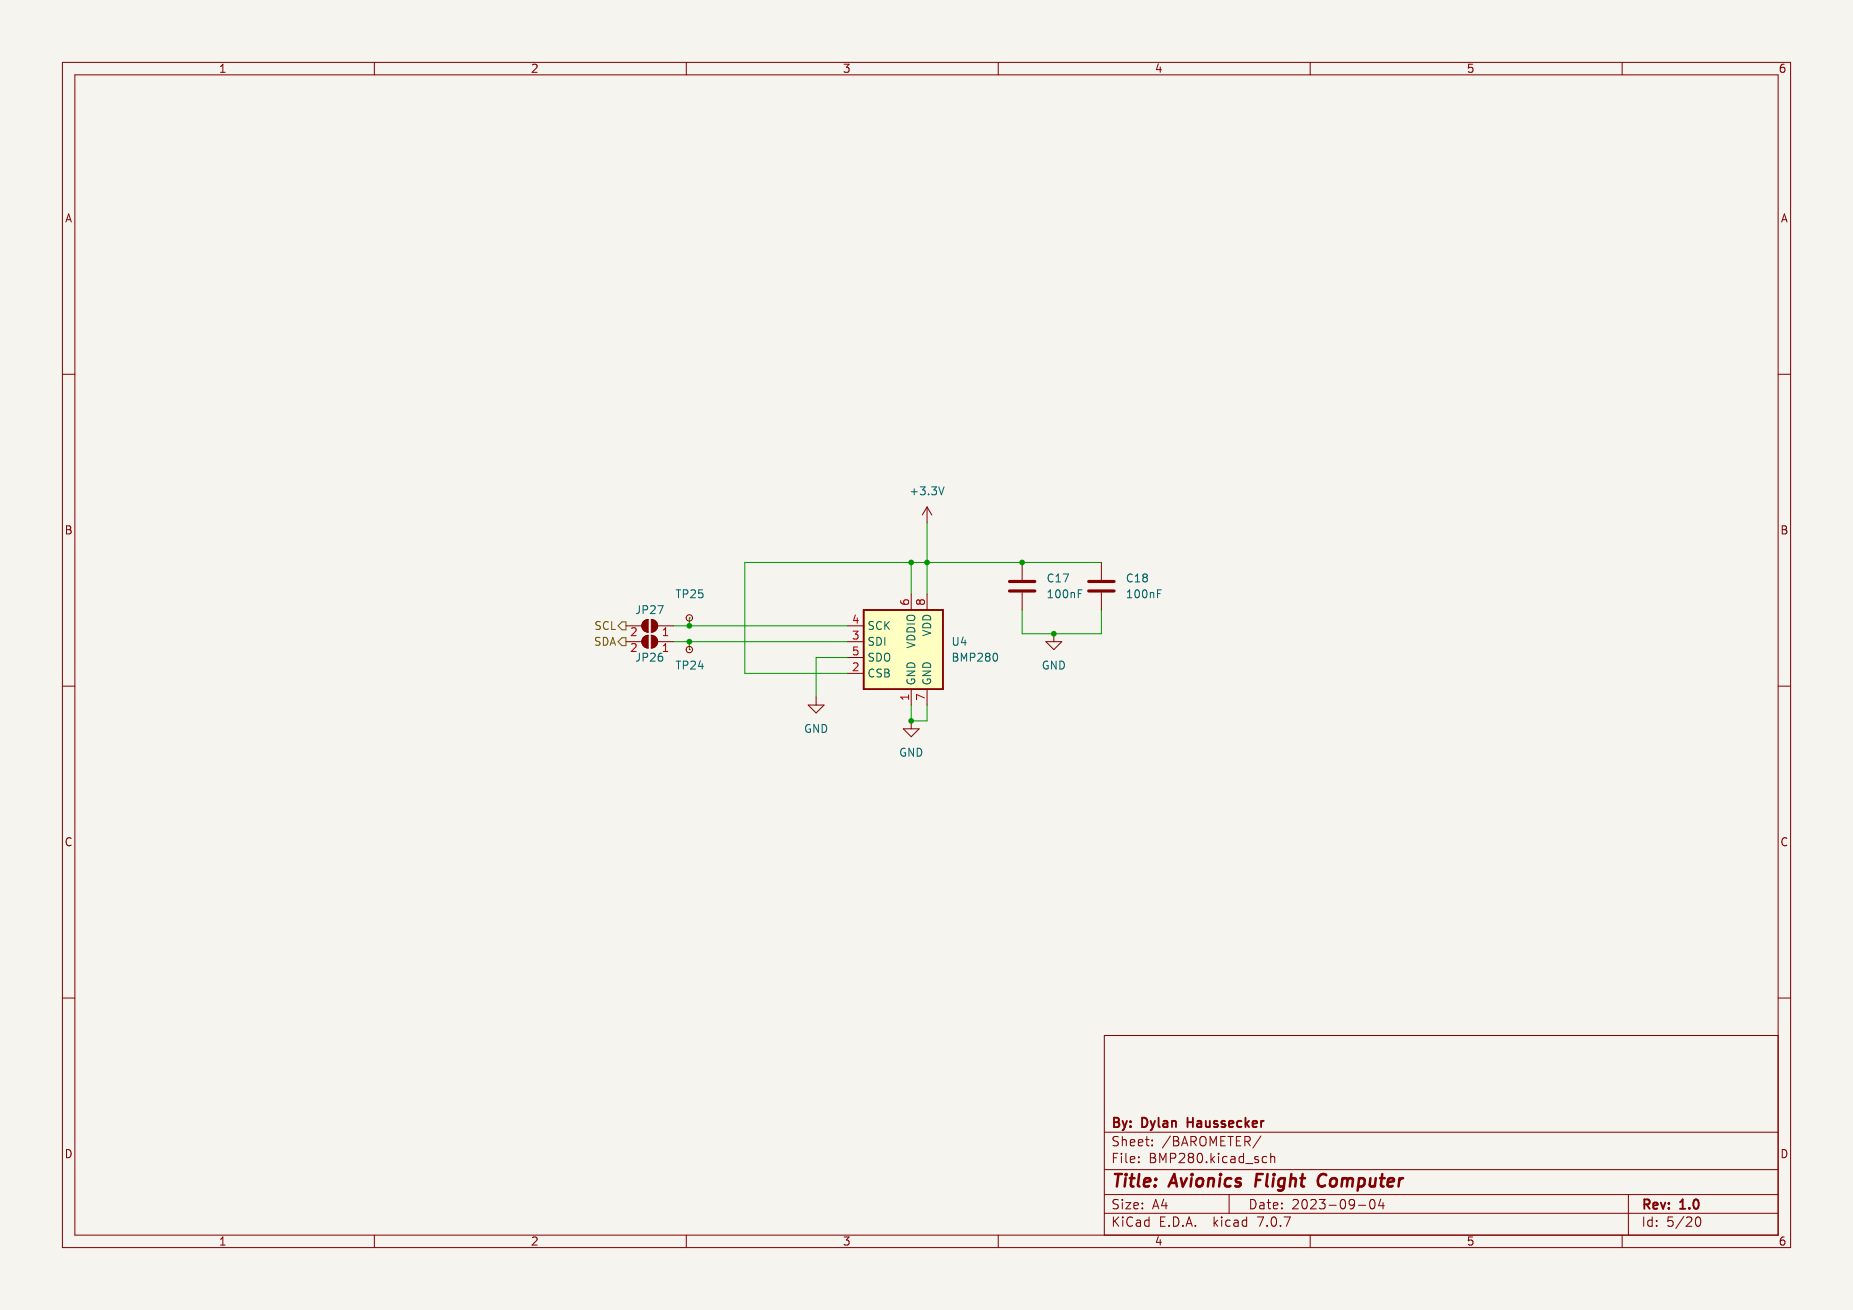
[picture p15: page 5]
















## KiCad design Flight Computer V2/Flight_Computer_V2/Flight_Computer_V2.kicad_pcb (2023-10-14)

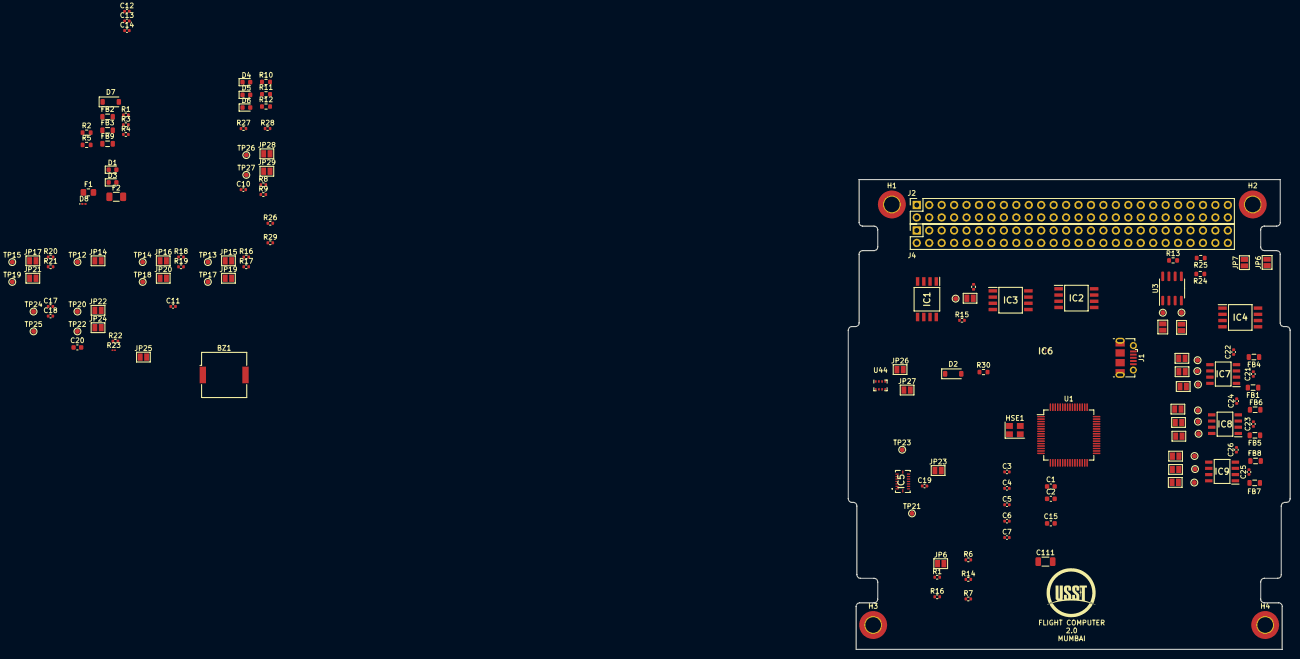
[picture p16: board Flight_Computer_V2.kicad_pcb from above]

Board: 4 copper layers, 90.2 x 95.9 mm, 154 parts (0 on the bottom side), 82 nets, no tracks yet.

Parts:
BZ1: Active_Buzzer; Buzzer_Murata_PKMCS0909E
C1, C2: 2.2uF; C_0603_1608Metric
C3, C4, C5, C6, C7, C11, C14, C19: 100n; C_0402_1005Metric
C10, C22, C24, C26: 0.1u; C_0402_1005Metric
C12, C13: 10p; C_0402_1005Metric
C15: 10n; C_0603_1608Metric
C17, C18: 100nF; C_0402_1005Metric
C20: 2.2u; C_0603_1608Metric
C21, C23, C25: 1p; C_0402_1005Metric
C111: 4u7; C_1206_3216Metric
D1, D6: RED; LED_0603_1608Metric
D2, D7: B5819W; D_SOD-123
D3: Red; LED_0603_1608Metric
D4: GREEN; LED_0603_1608Metric
D5: YELLOW; LED_0603_1608Metric
D8: RED; LED_0201_0603Metric
F1: 500 mA; Fuse_0805_2012Metric_Pad1.15x1.40mm_HandSolder
F2: 500 mA; Fuse_1206_3216Metric
FB1, FB4, FB5, FB6, FB7, FB8: Ferrite; L_0805_2012Metric
FB2, FB9: 600 @ 600 MHz; L_0805_2012Metric
FB3: 100 @ 100 MHz; L_0805_2012Metric
H1, H2, H3, H4: MountingHole_Pad; MountingHole_3.2mm_M3_ISO7380_Pad_TopBottom
HSE1: 16MHz; Crystal_SMD_3225-4Pin_3.2x2.5mm
IC1, IC2, IC3, IC4: MB85RC256VPF-G-JNERE2; SOIC127P798X210-8N
IC5: BMI088
IC6: MMC5603NJ
IC7, IC8, IC9: MAX31855KASA+T; SOIC127P600X175-8N
J1: USB_B_Micro; USB_Micro-B_Molex-105017-0001
J2, J4: Conn_02x26_Odd_Even; PinSocket_2x26_P2.54mm_Vertical
JP1, JP2, JP3, JP4, JP5, JP6, JP6#2, JP7, JP8, JP9, JP10, JP11, JP12, JP13, JP14, JP15, JP16, JP17, JP18, JP19, JP20, JP21, JP22, JP23, JP24, JP25, JP26, JP27, JP28, JP29: SolderJumper-2_P1.3mm_Open_Pad1.0x1.5mm
R1, R1#2, R6, R7, R14, R14#2, R15, R16, R16#2, R17, R18, R19, R20, R21: 10k; R_0402_1005Metric
R2, R30: 1.5k; R_0603_1608Metric
R3, R4: 1.5k; R_0402_1005Metric
R5: 2.2k; R_0603_1608Metric
R8, R9: 4.7k; R_0402_1005Metric
R10, R11, R12: 500; R_0603_1608Metric
R13: 120; R_0603_1608Metric
R22: 2.7k; R_0402_1005Metric
R23: 2.7k; R_01005_0402Metric
R24, R25: 2k; R_0603_1608Metric
R26, R27, R28, R29: 150; R_0402_1005Metric
TP1, TP2, TP3, TP4, TP5, TP6, TP7, TP8, TP9, TP10, TP11, TP12, TP13, TP14, TP15, TP16, TP17, TP18, TP19, TP20, TP21, TP22, TP23, TP24, TP25, TP26, TP27: TestPoint_Small; TestPoint_Pad_D1.0mm
U1: STM32F405RGTx; LQFP-64_10x10mm_P0.5mm
U3: MCP2562-E-SN; SOIC-8_3.9x4.9mm_P1.27mm
U44: BMP280; Bosch_LGA-8_2x2.5mm_P0.65mm_ClockwisePinNumbering

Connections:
3V3IN: D2.2 (A), J4.27, J4.28
5VIN: D7.2 (A), J2.47, J2.49, J4.25, J4.26
+3.3V: C10.1, C17.1, C18.1, D1.2 (A), FB2.2, JP6.1 (A), R3.1, R4.1, R8.2, R9.2, R24.1, R25.1, U3.5 (Vio), U44.2 (CSB), U44.6 (VDDIO), U44.8 (VDD)
+3.3VA: C14.1, C15.1, FB3.2, U1.13 (VDDA)
+3V3: C3.1, C4.1, C5.1, C6.1, C7.1, C11.1, C19.1, C20.1, C22.1, C24.1, C26.1, C111.1, FB3.1, IC1.8 (VDD), IC2.1 (A0), IC2.8 (VDD), IC3.2 (A1), IC3.8 (VDD), IC4.3 (A2), IC4.8 (VDD), IC5.3 (VDD), IC5.7 (PS), IC5.11 (VDDIO), IC6.B1 (VDD), IC7.4 (VCC), IC8.4 (VCC), IC9.4 (VCC), R6.1, R7.1, R14.1, R14#2.1, R15.1, R16.1, R16#2.1, R17.1, R18.1, R19.1, R20.1, R21.1, R22.1, R23.1, U1.1 (VBAT), U1.19 (VDD), U1.32 (VDD), U1.48 (VDD), U1.64 (VDD)
+5V: D8.2 (A), FB9.2, U3.3 (VDD)
/420_1: R26.2, U1.14 (PA0)
/420_2: R27.2, U1.15 (PA1)
/420_3: R28.2, U1.16 (PA2)
/420_4: R29.2, U1.17 (PA3)
/ACCELROMETER/SCL: J2.43, JP7.1 (A), JP18.2 (B), JP19.2 (B), JP20.2 (B), JP21.2 (B), JP24.2 (B), JP25.2 (B), JP27.2 (B), JP28.2 (B), R3.2, R14#2.2, R16.2, R18.2, R20.2, R25.2, U1.58 (PB6)
/ACCELROMETER/SDA: J2.41, JP6#2.1 (A), JP14.2 (B), JP15.2 (B), JP16.2 (B), JP17.2 (B), JP22.2 (B), JP23.2 (B), JP26.2 (B), JP29.1 (A), R4.2, R24.2, U1.59 (PB7)
/BUZZER: BZ1.1 (-), U1.41 (PA8)
/CAN CONTROLLER/CANH: J2.42, R13.1, U3.7 (CANH)
/CAN CONTROLLER/CANL: J2.44, R13.2, U3.6 (CANL)
/CAN CONTROLLER/CAN_RX: JP5.2 (B), U1.61 (PB8)
/CAN CONTROLLER/CAN_TX: JP4.2 (B), U1.62 (PB9)
/GREEN: R10.1, U1.20 (PA4)
/MICROCONTROLLER/BOOT0: JP6.2 (B), R1.2, R1#2.2, U1.60 (BOOT0)
/MICROCONTROLLER/HSC_IN: C12.1, HSE1.1, U1.5 (PH0)
/MICROCONTROLLER/HSC_OUT: C13.1, HSE1.3, U1.6 (PH1)
/MICROCONTROLLER/PWR_LED_K: D1.1 (K), D8.1 (K), R2.1, R30.1
/MICROCONTROLLER/SPI1_CLK: JP3.2 (B), JP10.2 (B), JP13.2 (B), U1.21 (PA5)
/MICROCONTROLLER/SPI1_MISO: JP1.2 (B), JP8.2 (B), JP11.2 (B), U1.22 (PA6)
/MICROCONTROLLER/USB_D+: J1.3 (D+), U1.45 (PA12)
/MICROCONTROLLER/USB_D-: J1.2 (D-), U1.44 (PA11)
/MICROCONTROLLER/VCAP1: C1.1, U1.31 (VCAP_1)
/MICROCONTROLLER/VCAP2: C2.1, U1.47 (VCAP_2)
/RED: R12.1, U1.27 (PB1)
/TCSS1: JP2.2 (B), U1.8 (PC0)
/TCSS2: JP9.2 (B), U1.9 (PC1)
/TCSS3: JP12.2 (B), U1.10 (PC2)
/WP1: IC1.7 (WP), U1.11 (PC3)
/WP2: IC2.7 (WP), U1.24 (PC4)
/WP3: IC3.7 (WP), U1.25 (PC5)
/WP4: IC4.7 (WP), U1.37 (PC6)
/YELLOW: R11.1, U1.26 (PB0)
GND: BZ1.2 (+), C1.2, C2.2, C10.2, C11.2, C12.2, C13.2, C14.2, C15.2, C17.2, C18.2, C19.2, C20.2, C22.2, C24.2, C26.2, D4.1 (K), D5.1 (K), D6.1 (K), H1.1, H2.1, H3.1, H4.1, HSE1.2, HSE1.4, IC1.4 (VSS), IC2.4 (VSS), IC3.4 (VSS), IC4.4 (VSS), IC5.4 (GNDA), IC5.6 (GNDIO), IC5.10 (SDO2), IC5.15 (SDO1), IC6.A1 (VSA), IC7.1 (GND), IC8.1 (GND), IC9.1 (GND), J1.5 (GND), J4.9, J4.14, J4.17, J4.29, J4.30, J4.32, J4.48, J4.49, R1#2.1, R2.2, R5.2, R26.1, R27.1, R28.1, R29.1, R30.2, U1.12 (VSSA), U1.18 (VSS), U1.63 (VSS), U3.2 (VSS), U3.8 (STBY), U44.1 (GND), U44.5 (SDO), U44.7 (GND)
unnamed: C3.2, C4.2, C5.2, C6.2, C7.2, C111.2
unnamed: D2.1 (K), F1.1
unnamed: D3.2 (A), U1.33 (PB12)
unnamed: D3.1 (K), R5.1
unnamed: D4.2 (A), R10.2
unnamed: D5.2 (A), R11.2
unnamed: D6.2 (A), R12.2
unnamed: D7.1 (K), F2.1
unnamed: F1.2, FB2.1
unnamed: F2.2, FB9.1
unnamed: IC1.6 (SCL), JP18.1 (A), R6.2, TP16.1
unnamed: IC1.5 (SDA), JP14.1 (A), R15.2, TP12.1
unnamed: IC2.6 (SCL), JP19.1 (A), R7.2, TP17.1
unnamed: IC2.5 (SDA), JP15.1 (A), R17.2, TP13.1
unnamed: IC3.6 (SCL), JP20.1 (A), R14.2, TP18.1
unnamed: IC3.5 (SDA), JP16.1 (A), R19.2, TP14.1
unnamed: IC4.6 (SCL), JP21.1 (A), R16#2.2, TP19.1
unnamed: IC4.5 (SDA), JP17.1 (A), R21.2, TP15.1
unnamed: IC5.8 (SCL/SCK), JP25.1 (A), TP23.1
unnamed: IC5.9 (SDA/SDI), JP23.1 (A), TP21.1
unnamed: IC6.A2 (SCL), JP24.1 (A), R22.2, TP22.1
unnamed: IC6.B2 (SDA), JP22.1 (A), R23.2, TP20.1
unnamed: IC7.5 (SCK), JP3.1 (A), TP3.1
unnamed: IC7.7 (SO), JP1.1 (A), TP1.1
unnamed: C21.2, FB4.2, IC7.3 (T+)
unnamed: C21.1, FB1.2, IC7.2 (T-)
unnamed: IC7.6 (~CS), JP2.1 (A), TP2.1
unnamed: IC8.5 (SCK), JP10.1 (A), TP8.1
unnamed: IC8.7 (SO), JP8.1 (A), TP6.1
unnamed: C23.2, FB6.2, IC8.3 (T+)
unnamed: C23.1, FB5.2, IC8.2 (T-)
unnamed: IC8.6 (~CS), JP9.1 (A), TP7.1
unnamed: IC9.5 (SCK), JP13.1 (A), TP11.1
unnamed: IC9.7 (SO), JP11.1 (A), TP9.1
unnamed: C25.2, FB8.2, IC9.3 (T+)
unnamed: C25.1, FB7.2, IC9.2 (T-)
unnamed: IC9.6 (~CS), JP12.1 (A), TP10.1
unnamed: JP4.1 (A), TP4.1, U3.1 (TXD)
unnamed: JP5.1 (A), TP5.1, U3.4 (RXD)
unnamed: JP26.1 (A), TP24.1, U44.3 (SDI)
unnamed: JP27.1 (A), TP25.1, U44.4 (SCK)
unnamed: JP28.1 (A), TP26.1
unnamed: JP29.2 (B), TP27.1
VBUS: J1.1 (VBUS), J4.35, J4.36

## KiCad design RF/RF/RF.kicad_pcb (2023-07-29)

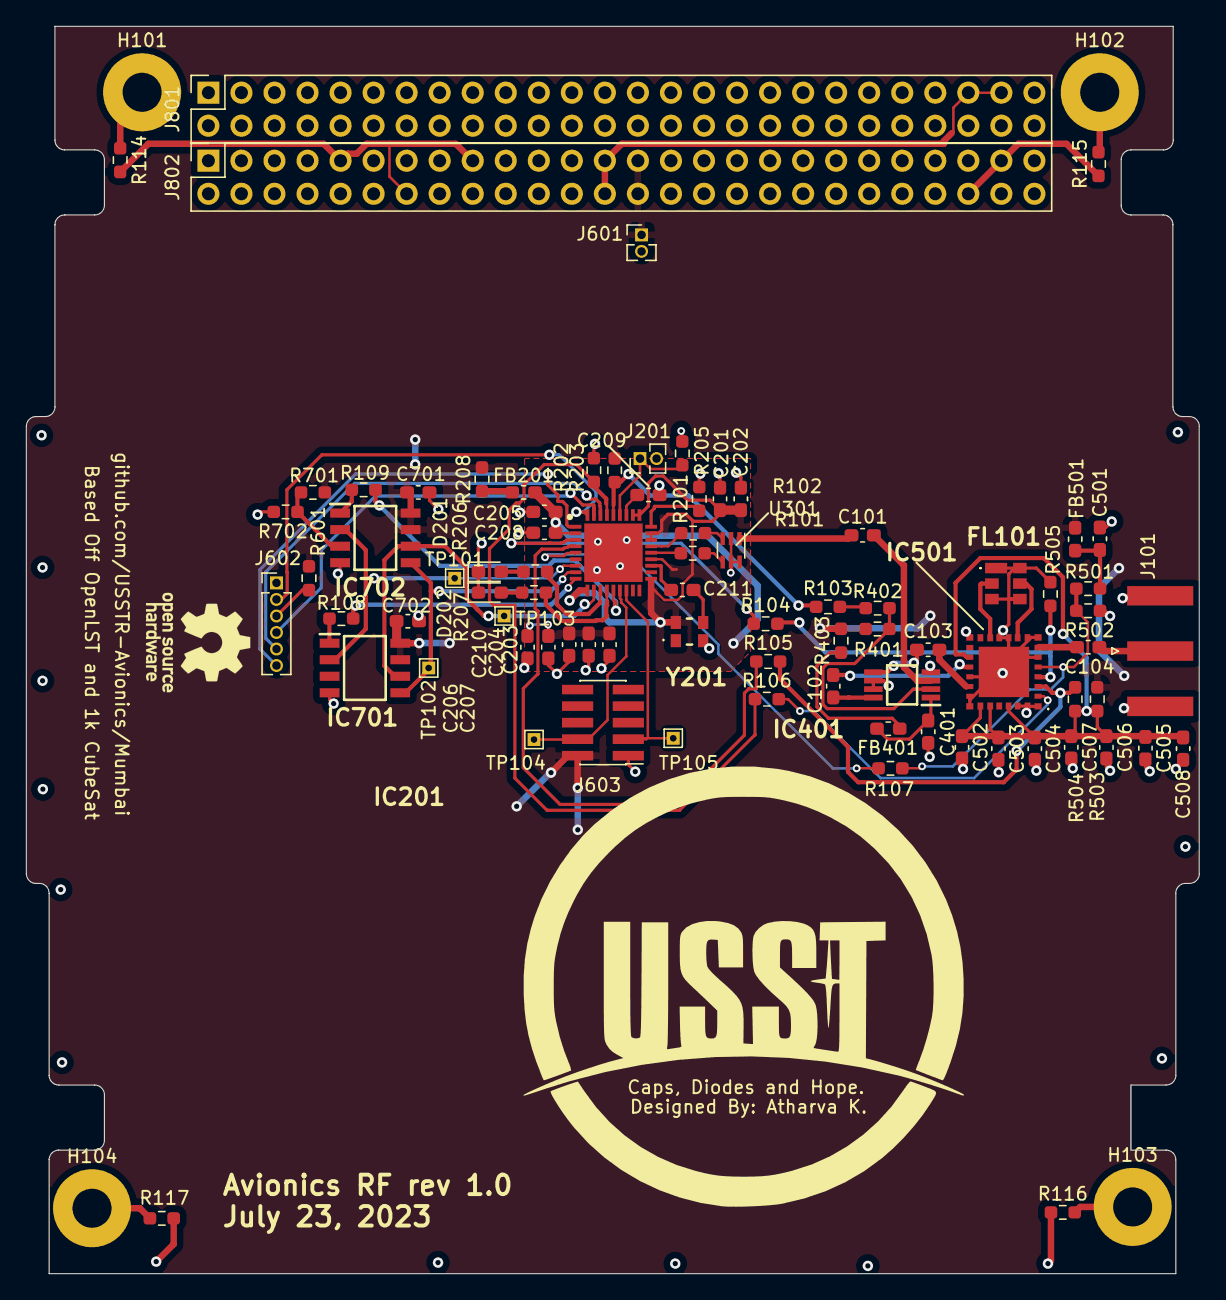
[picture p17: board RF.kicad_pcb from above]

Board: 4 copper layers, 90.2 x 95.9 mm, 86 parts (0 on the bottom side), 62 nets.

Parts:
C101, C102, C103, C104, C207, C208: 220pF; C_0603_1608Metric_Pad1.08x0.95mm_HandSolder
C201, C202, C209, C507: 1uF; C_0603_1608Metric_Pad1.08x0.95mm_HandSolder
C203, C204, C205, C206, C210, C401, C501, C505, C506, C508, C701, C702: 0.1uF; C_0603_1608Metric_Pad1.08x0.95mm_HandSolder
C211: 0.01uF; C_0603_1608Metric_Pad1.08x0.95mm_HandSolder
C502, C503: 47uF; C_0603_1608Metric_Pad1.08x0.95mm_HandSolder
C504: 4.7uF; C_0603_1608Metric_Pad1.08x0.95mm_HandSolder
D201, D202: LED; LED_0603_1608Metric_Pad1.05x0.95mm_HandSolder
FB201: Z = 1k@ 100MHz; L_0603_1608Metric_Pad1.05x0.95mm_HandSolder
FB401, FB501: Z = 1k @ 100M; L_0603_1608Metric_Pad1.05x0.95mm_HandSolder
FL101: SF2446E
H101, H102, H103, H104: MountingHole_Pad; MountingHole_3mm_Pad
IC201: CC1110F16RHHR; QFN50P600X600X100-37N-D
IC401: PE4250MLI-Z; SOP65P488X107-8N
IC501: RFFM6406SR; RFFM6403
IC701: 23K256-I_SN; SOIC127P600X175-8N
IC702: SST25VF512A-33-4C-SAE; SOIC127P600X175-8N
J101: Conn_Coaxial; SMA_Amphenol_132289_EdgeMount
J201, J601: Conn_01x02; PinHeader_1x02_P1.27mm_Vertical
J602: Conn_01x06; PinHeader_1x06_P1.27mm_Vertical
J603: Conn_02x05_Odd_Even; PinHeader_2x05_P1.27mm_Vertical_SMD
J801, J802: Conn_02x26_Odd_Even; PinSocket_2x26_P2.54mm_Vertical
R101, R102, R103, R104, R105, R106, R107, R108, R109, R208, R402, R403, R503: 0R; R_0603_1608Metric_Pad0.98x0.95mm_HandSolder
R114, R115, R116, R117, R401, R601, R701: DNP; R_0603_1608Metric_Pad0.98x0.95mm_HandSolder
R201: 56k 1%; R_0603_1608Metric_Pad0.98x0.95mm_HandSolder
R202, R203: 10k 1%; R_0603_1608Metric_Pad0.98x0.95mm_HandSolder
R205, R702: 10k; R_0603_1608Metric_Pad0.98x0.95mm_HandSolder
R206, R207, R504, R505: 1k; R_0603_1608Metric_Pad0.98x0.95mm_HandSolder
R501: 3.09k 1%; R_0603_1608Metric_Pad0.98x0.95mm_HandSolder
R502: 6.65k 1%; R_0603_1608Metric_Pad0.98x0.95mm_HandSolder
TP101: MISO; TestPoint_THTPad_1.0x1.0mm_Drill0.5mm
TP102: MOSI; TestPoint_THTPad_1.0x1.0mm_Drill0.5mm
TP103: SCK; TestPoint_THTPad_1.0x1.0mm_Drill0.5mm
TP104: CC_DD; TestPoint_THTPad_1.0x1.0mm_Drill0.5mm
TP105: CC_DC; TestPoint_THTPad_1.0x1.0mm_Drill0.5mm
U301: 0433BM15A0001; Balun_Johanson_0896BM15A0001
Y201: TG2520SMN 27.000M-MCGNNM3; TG2520SMN25000MMCGNNM3

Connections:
+3.3V: C701.1, C702.1, FB501.2, IC701.7 (~HOLD), IC701.8 (VCC), IC702.7 (HOLD#), IC702.8 (VDD), J601.1, J603.2, J802.27, J802.28, R203.1, R208.2, R401.1, R403.2, R503.2, R601.2, R701.1
+3.3VA: C201.1, C202.1, C203.1, C204.1, C205.1, C206.1, C207.1, C208.1, C210.1, FB201.2, IC201.2 (DVDD_1), IC201.10 (DVDD_2), IC201.19 (AVDD_1), IC201.22 (AVDD_2), IC201.25 (AVDD_3), IC201.26 (AVDD_4), IC201.28 (GUARD), IC201.29 (AVDD_DREG), J201.2, Y201.4 (VCC)
+5V: J801.47, J801.49, J802.25, J802.26
/Balun/CC_RF_N: R102.2, U301.3
/Balun/CC_RF_P: R101.2, U301.4
/Balun/UNBALANCED_RF: C101.1, U301.1
/CC1110/AIN0: IC201.5 (P0_0), R107.1
/CC1110/CC_DC: IC201.16 (P2_2), J603.3, TP105.1
/CC1110/CC_DD: IC201.15 (P2_1), J603.4, TP104.1
/CC1110/CC_RF_N: IC201.24 (RF_N), R102.1
/CC1110/CC_RF_P: IC201.23 (RF_P), R101.1
/CC1110/CC_SOC_OC: C211.2, IC201.21 (XOSC_Q1)
/CC1110/LST_TX_MODE: IC201.33 (P1_6), R106.1, R202.1
/CC1110/RF_BYP: IC201.3 (P1_1), R104.1
/CC1110/RF_EN: IC201.4 (P1_0), R105.1
/CC1110/UART0_CTS: IC201.1 (P1_2), J602.6
/CC1110/UART0_RTS: IC201.36 (P1_3), J602.2
/CC1110/UART0_RX: IC201.35 (P1_4), J602.4
/CC1110/UART0_TX: IC201.34 (P1_5), J602.5
/CC1110/~FLASH_CS: IC201.14 (P2_0), R109.1
/CC1110/~LST_RX_MODE: IC201.32 (P1_7), R103.1, R203.2
/CC1110/~SRAM_CS: IC201.9 (P0_4), R108.1
/External Memory/~FLASH_CS: IC702.1 (CE#), R109.2
/External Memory/~SRAM_CS: IC701.1 (~CS), R108.2
/MISO: IC201.7 (P0_2), IC701.2 (SO), IC702.2 (SO), TP101.1
/MOSI: IC201.8 (P0_3), IC701.5 (SI), IC702.5 (SI), TP102.1
/RF Front End/ANTENNA: C104.1, IC501.7 (ANT)
/RF Front End/LST_TX_MODE: IC501.2 (TR), R106.2
/RF Front End/PA_VAPC: IC501.5 (VAPC), R107.2, R501.2, R502.1
/RF Front End/RF_BYP: IC501.4 (BYP), R104.2, R505.2
/RF Front End/RF_EN: IC501.3 (EN), R105.2, R504.1
/RF Front End/RX: C102.2, IC501.18 (RX)
/RF Front End/SAW1: FL101.5 (OUTPUT), IC501.10 (SAW1)
/RF Front End/SAW2: FL101.2 (INPUT), IC501.13 (SAW2)
/RF Front End/TX: C103.2, IC501.20 (TX)
/RF Switch/RX: C102.1, IC401.8 (RF2)
/RF Switch/TX: C103.1, IC401.5 (RF1)
/RF Switch/UNBALANCED_RF: C101.2, IC401.3 (RFC)
/RF Switch/~LST_RX_MODE: R103.2, R402.1
/SCK: IC201.11 (P0_5), IC701.6 (SCK), IC702.6 (SCK), TP103.1
GND: C201.2, C202.2, C203.2, C204.2, C205.2, C206.2, C207.2, C208.2, C209.2, C210.2, C401.2, C501.2, C502.2, C503.2, C504.2, C505.2, C506.2, C507.2, C508.2, C701.2, C702.2, D201.1 (K), D202.1 (K), FL101.1 (GND_1), FL101.3 (GND_2), FL101.4 (GND_3), FL101.6 (GND_4), IC201.37 (AGND), IC401.4 (N/C_OR_GND), IC401.6 (GND_1), IC401.7 (GND_2), IC501.1 (GND_1), IC501.6 (GND_2), IC501.8 (GND_3), IC501.9 (GND_4), IC501.11 (GND_5), IC501.12 (GND_6), IC501.15 (GND_7), IC501.19 (GND_8), IC501.21 (GND_9), IC501.22 (GND_10), IC501.27 (GND_11), IC501.28 (GND_12), IC501.29 (EP), IC701.4 (VSS), IC702.4 (VSS), J101.2 (Ext), J601.2, J602.1, J603.1, J802.9, J802.14, J802.17, J802.29, J802.30, J802.32, J802.48, J802.49, R114.1, R115.1, R116.1, R117.1, R201.2, R202.2, R205.2, R502.2, R505.1, R702.2, U301.2 (GND), U301.5 (GND), U301.6 (GND), Y201.2 (GND)
unnamed: C501.1, FB501.1, R501.1
unnamed: D201.2 (A), R206.2
unnamed: D202.2 (A), R207.2
unnamed: FB201.1, R208.1
unnamed: FB401.1, R403.1
unnamed: H101.1, R114.2
unnamed: H102.1, R115.2
unnamed: H103.1, R116.2
unnamed: H104.1, R117.2
unnamed: C209.1, IC201.30 (DCOUPL)
unnamed: IC201.12 (P0_6), R206.1
unnamed: IC201.13 (P0_7), R207.1
unnamed: IC201.27 (RBIAS), R201.1
unnamed: IC201.31 (RESET_N), J201.1, R205.1
unnamed: IC401.2 (V1), R401.2, R402.2
unnamed: C401.1, FB401.2, IC401.1 (V2)
unnamed: C502.1, C503.1, C504.1, C505.1, C506.1, C507.1, C508.1, IC501.17 (VCC_RX), IC501.23 (VDD), IC501.24 (VCC_TX1), IC501.26 (VCC_TX2), R503.1, R504.2
unnamed: IC702.3 (WP#), R701.2, R702.1
unnamed: C104.2, J101.1 (In)
unnamed: J602.3, R601.1
unnamed: C211.1, Y201.3 (OUT)

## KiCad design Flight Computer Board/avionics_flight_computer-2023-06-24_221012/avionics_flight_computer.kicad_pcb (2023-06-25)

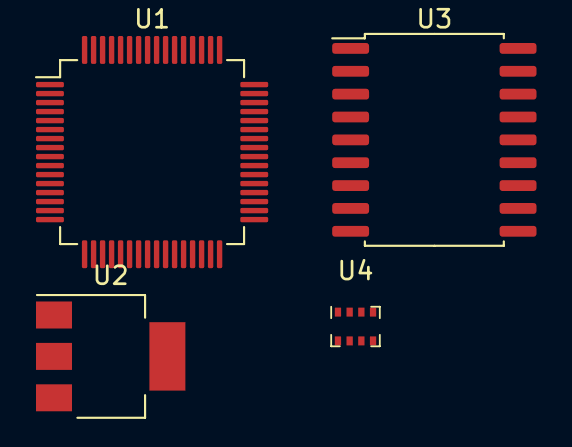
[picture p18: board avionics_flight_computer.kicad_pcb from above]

Board: 2 copper layers, 4 parts (0 on the bottom side), 2 nets, no tracks yet.

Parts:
U1: STM32F405RGTx; LQFP-64_10x10mm_P0.5mm
U2: AMS1117-3.3; SOT-223-3_TabPin2
U3: MCP2515-xSO; SOIC-18W_7.5x11.6mm_P1.27mm
U4: BMP280; Bosch_LGA-8_2x2.5mm_P0.65mm_ClockwisePinNumbering

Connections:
3.3V: U1.1 (VBAT), U1.19 (VDD), U1.32 (VDD), U1.48 (VDD), U1.64 (VDD), U2.2 (VO), U4.2 (CSB), U4.6 (VDDIO), U4.8 (VDD)
GND: U1.12 (VSSA), U1.18 (VSS), U1.63 (VSS), U2.1 (GND), U3.9 (VSS), U4.1 (GND), U4.5 (SDO), U4.7 (GND)

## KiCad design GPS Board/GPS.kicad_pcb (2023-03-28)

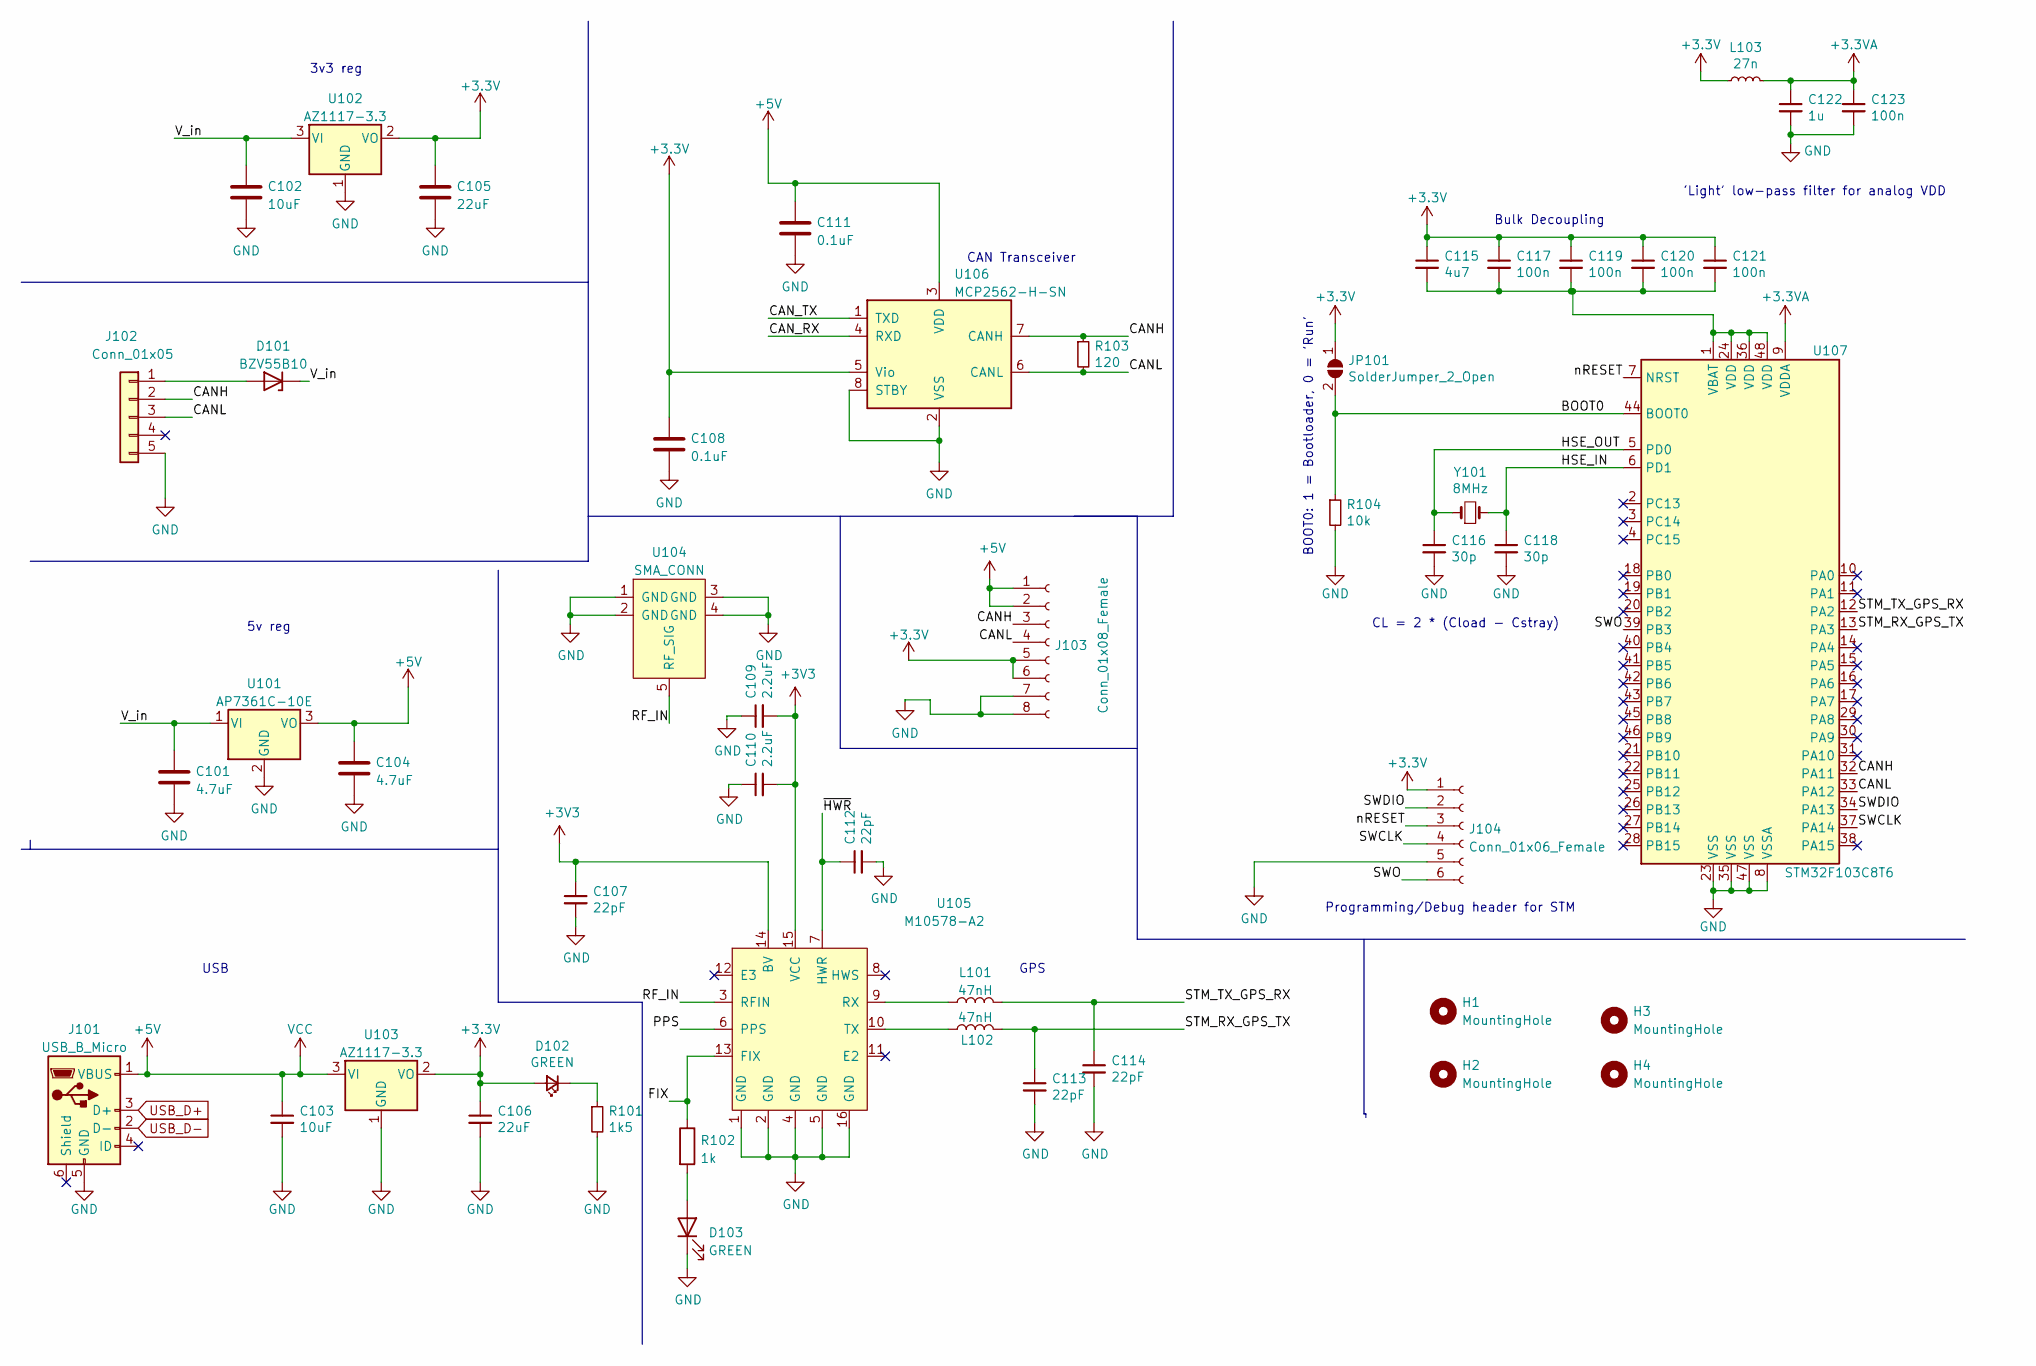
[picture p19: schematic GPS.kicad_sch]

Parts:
C101, C104: 4.7uF; C_0805_2012Metric
C102: 10uF; C_0805_2012Metric
C103: 10uF; C_0603_1608Metric; LCSC Part # C15849
C105: 22uF; C_0805_2012Metric
C106: 22uF; C_0805_2012Metric; LCSC Part # C15849
C107, C112, C113, C114: 22pF; C_0805_2012Metric; LCSC Part # C15849
C108, C111: 0.1uF; C_0805_2012Metric
C109, C110: 2.2uF; C_0805_2012Metric; LCSC Part # C15849
C115: 4u7; C_0805_2012Metric_Pad1.18x1.45mm_HandSolder; LCSC Part # C19666
C116, C118: 30p; C_0805_2012Metric_Pad1.18x1.45mm_HandSolder; LCSC Part # C1570
C117, C119, C120, C121, C123: 100n; C_0805_2012Metric_Pad1.18x1.45mm_HandSolder; LCSC Part # C1525
C122: 1u; C_0805_2012Metric_Pad1.18x1.45mm_HandSolder; LCSC Part # C52923
D101: BZV55B10; D_MiniMELF
D102: GREEN; LED_0805_2012Metric_Pad1.15x1.40mm_HandSolder; LCSC Part # C72043
D103: GREEN; LED_0805_2012Metric_Pad1.15x1.40mm_HandSolder
H1, H2, H3, H4: MountingHole; MountingHole_3.2mm_M3
J101: USB_B_Micro; USB_Micro-B_Wuerth_629105150521
J102: Conn_01x05; PinHeader_1x05_P1.27mm_Horizontal
J103: Conn_01x08_Female; PinHeader_1x08_P1.27mm_Horizontal
J104: Conn_01x06_Female; Tag-Connect_TC2030-IDC-FP_2x03_P1.27mm_Vertical
JP101: SolderJumper_2_Open; SolderJumper-2_P1.3mm_Open_Pad1.0x1.5mm
L101, L102: 47nH; L_0805_2012Metric_Pad1.15x1.40mm_HandSolder
L103: 27n; L_0402_1005Metric; LCSC Part # C18830
R101: 1k5; R_0805_2012Metric; LCSC Part # C22843
R102: 1k; R_0805_2012Metric_Pad1.20x1.40mm_HandSolder
R103: 120; R_0805_2012Metric; LCSC Part # C25744
R104: 10k; R_0805_2012Metric_Pad1.20x1.40mm_HandSolder; LCSC Part # C25744
U101: AP7361C-10E; SOT-223-3_TabPin2
U102, U103: AZ1117-3.3; SOT-223
U104: SMA_CONN; connector_SMA_3-1478978-1
U105: M10578-A2
U106: MCP2562-H-SN; SOIC-8_3.9x4.9mm_P1.27mm
U107: STM32F103C8T6; LQFP-48_7x7mm_P0.5mm; LCSC Part # C8734
Y101: 8MHz; Crystal_SMD_5032-2Pin_5.0x3.2mm; LCSC Part # C115962

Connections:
+3.3V: C105.1, C106.1, C108.1, C115.1, C117.1, C119.1, C120.1, C121.1, D102.2 (A), J103.5, J103.6, J104.1, JP101.1 (A), L103.1, U102.2 (VO), U103.2 (VO), U106.5 (Vio)
+3.3VA: C122.1, C123.1, L103.2, U107.9 (VDDA)
+3V3: C107.1, C109.2, C110.2, U105.14 (BV), U105.15 (VCC)
+5V: C103.1, C104.1, C111.1, J101.1 (VBUS), J103.1, J103.2, U101.3 (VO), U103.3 (VI), U106.3 (VDD)
/BOOT0: JP101.2 (B), R104.1, U107.44 (BOOT0)
/CANH: J102.2, J103.3, R103.1, U106.7 (CANH), U107.32 (PA11)
/CANL: J102.3, J103.4, R103.2, U106.6 (CANL), U107.33 (PA12)
/CAN_RX: U106.4 (RXD)
/CAN_TX: U106.1 (TXD)
/FIX: R102.1, U105.13 (FIX)
/HSE_IN: C118.1, U107.6 (PD1), Y101.2
/HSE_OUT: C116.1, U107.5 (PD0), Y101.1
/PPS: U105.6 (PPS)
/RF_IN: U104.5 (RF_SIG), U105.3 (RFIN)
/STM_RX_GPS_TX: C113.1, L102.2, U107.13 (PA3)
/STM_TX_GPS_RX: C114.1, L101.2, U107.12 (PA2)
/SWCLK: J104.4, U107.37 (PA14)
/SWDIO: J104.2, U107.34 (PA13)
/SWO: J104.6, U107.39 (PB3)
/V_in: C101.1, C102.1, D101.1 (K), U101.1 (VI), U102.3 (VI)
/nRESET: J104.3, U107.7 (NRST)
/~HWR: C112.1, U105.7 (HWR)
GND: C101.2, C102.2, C103.2, C104.2, C105.2, C106.2, C107.2, C108.2, C109.1, C110.1, C111.2, C112.2, C113.2, C114.2, C116.2, C118.2, C122.2, C123.2, D103.1 (K), J101.5 (GND), J102.5, J103.7, J103.8, J104.5, R101.2, R104.2, U101.2 (GND), U102.1 (GND), U103.1 (GND), U104.1 (GND), U104.2 (GND), U104.3 (GND), U104.4 (GND), U105.1 (GND), U105.2 (GND), U105.4 (GND), U105.5 (GND), U105.16 (GND), U106.2 (VSS), U106.8 (STBY), U107.8 (VSSA), U107.23 (VSS), U107.35 (VSS), U107.47 (VSS)
unnamed: C115.2, C117.2, C119.2, C120.2, C121.2, U107.1 (VBAT), U107.24 (VDD), U107.36 (VDD), U107.48 (VDD)
unnamed: D101.2 (A), J102.1
unnamed: D102.1 (K), R101.1
unnamed: D103.2 (A), R102.2
unnamed: L101.1, U105.9 (RX)
unnamed: L102.1, U105.10 (TX)

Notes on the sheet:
USB
CAN Transceiver
'Light' low-pass filter for analog VDD
5v reg
Bulk Decoupling
CL = 2 * (Cload - Cstray)
Programming/Debug header for STM
GPS
3v3 reg
BOOT0: 1 = Bootloader, 0 = 'Run'

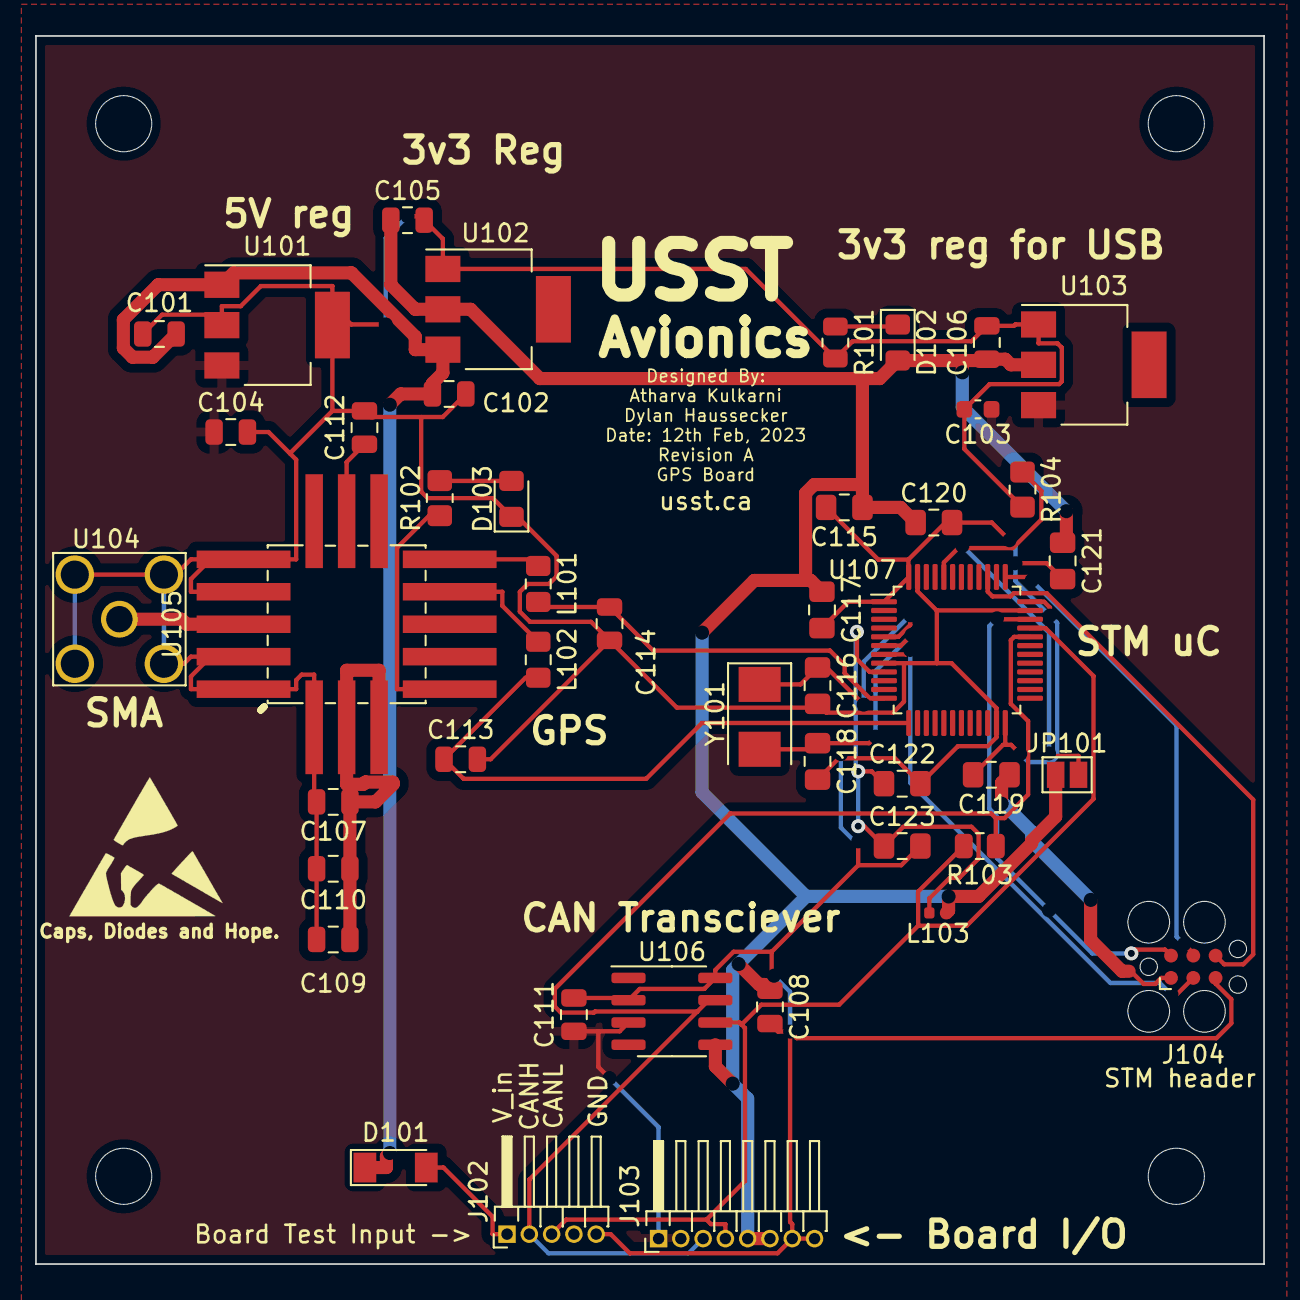
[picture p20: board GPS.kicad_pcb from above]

Board: 2 copper layers, 70.0 x 70.0 mm, 49 parts (0 on the bottom side), 26 nets.

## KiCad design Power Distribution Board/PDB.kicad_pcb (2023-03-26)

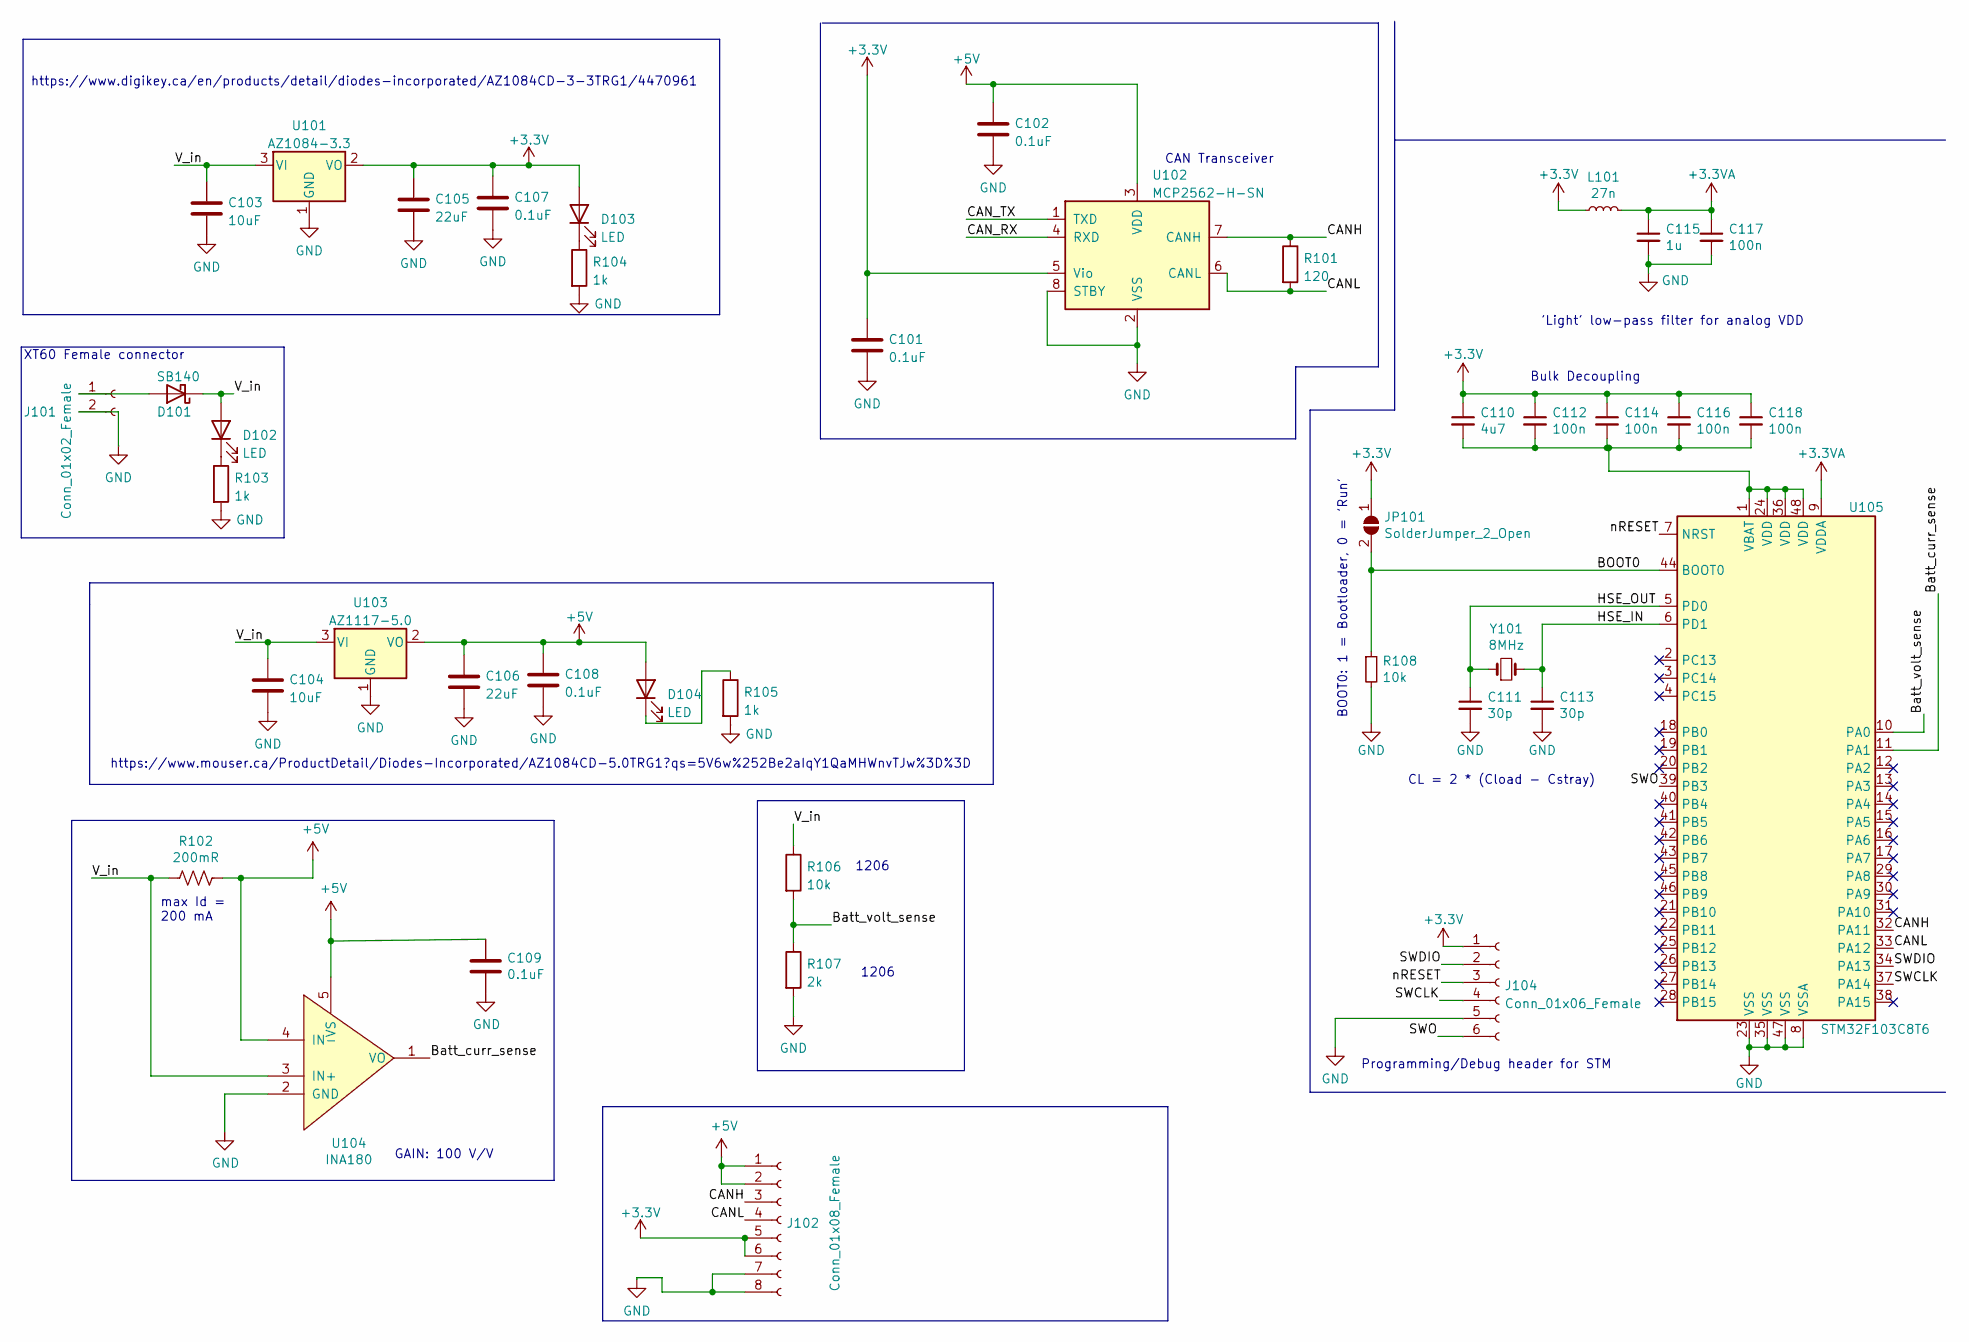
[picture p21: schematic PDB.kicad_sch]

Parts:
C101, C102, C107, C108, C109: 0.1uF; C_0805_2012Metric_Pad1.18x1.45mm_HandSolder
C103, C104: 10uF; C_0805_2012Metric_Pad1.18x1.45mm_HandSolder
C105, C106: 22uF; C_0805_2012Metric_Pad1.18x1.45mm_HandSolder
C110: 4u7; C_0805_2012Metric_Pad1.18x1.45mm_HandSolder; LCSC Part # C19666
C111, C113: 30p; C_0805_2012Metric_Pad1.18x1.45mm_HandSolder; LCSC Part # C1570
C112, C114, C116, C117, C118: 100n; C_0805_2012Metric_Pad1.18x1.45mm_HandSolder; LCSC Part # C1525
C115: 1u; C_0805_2012Metric_Pad1.18x1.45mm_HandSolder; LCSC Part # C52923
D101: SB140; D_DO-41_SOD81_P10.16mm_Horizontal
D102, D103, D104: LED; LED_0805_2012Metric_Pad1.15x1.40mm_HandSolder
J101: Conn_01x02_Female; AMASS_XT60PW-F_1x02_P7.20mm_Horizontal
J102: Conn_01x08_Female; PinHeader_1x08_P1.27mm_Horizontal
J104: Conn_01x06_Female; Tag-Connect_TC2030-IDC-FP_2x03_P1.27mm_Vertical
JP101: SolderJumper_2_Open; SolderJumper-2_P1.3mm_Open_Pad1.0x1.5mm
L101: 27n; L_0402_1005Metric; LCSC Part # C18830
R101: 120; R_0805_2012Metric_Pad1.20x1.40mm_HandSolder
R102: 200mR; R_0805_2012Metric_Pad1.20x1.40mm_HandSolder
R103, R104, R105: 1k; R_0805_2012Metric_Pad1.20x1.40mm_HandSolder
R106: 10k; R_1206_3216Metric_Pad1.30x1.75mm_HandSolder
R107: 2k; R_1206_3216Metric_Pad1.30x1.75mm_HandSolder
R108: 10k; R_0805_2012Metric_Pad1.20x1.40mm_HandSolder; LCSC Part # C25744
U101: AZ1084-3.3; TO-252-2
U102: MCP2562-H-SN; SOIC-8_3.9x4.9mm_P1.27mm
U103: AZ1117-5.0; TO-252-3_TabPin2
U104: INA180; SOT-23-5_HandSoldering
U105: STM32F103C8T6; LQFP-48_7x7mm_P0.5mm; LCSC Part # C8734
Y101: 8MHz; Crystal_SMD_5032-2Pin_5.0x3.2mm; LCSC Part # C115962

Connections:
+3.3V: C101.1, C105.1, C107.1, C110.1, C112.1, C114.1, C116.1, C118.1, D103.2 (A), J102.5, J102.6, J104.1, JP101.1 (A), L101.1, U101.2 (VO), U102.5 (Vio)
+3.3VA: C115.1, C117.1, L101.2, U105.9 (VDDA)
+5V: C102.1, C106.1, C108.1, C109.1, D104.2 (A), J102.1, J102.2, R102.1, U102.3 (VDD), U103.2 (VO), U104.4 (IN-), U104.5 (VS)
/BOOT0: JP101.2 (B), R108.1, U105.44 (BOOT0)
/Batt_curr_sense: U104.1 (VO), U105.11 (PA1)
/Batt_volt_sense: R106.2, R107.1, U105.10 (PA0)
/CANH: J102.3, R101.1, U102.7 (CANH), U105.32 (PA11)
/CANL: J102.4, R101.2, U102.6 (CANL), U105.33 (PA12)
/CAN_RX: U102.4 (RXD)
/CAN_TX: U102.1 (TXD)
/HSE_IN: C113.1, U105.6 (PD1), Y101.2
/HSE_OUT: C111.1, U105.5 (PD0), Y101.1
/SWCLK: J104.4, U105.37 (PA14)
/SWDIO: J104.2, U105.34 (PA13)
/SWO: J104.6, U105.39 (PB3)
/V_in: C103.1, C104.1, D101.1 (K), D102.2 (A), R102.2, R106.1, U101.3 (VI), U103.3 (VI), U104.3 (IN+)
/nRESET: J104.3, U105.7 (NRST)
GND: C101.2, C102.2, C103.2, C104.2, C105.2, C106.2, C107.2, C108.2, C109.2, C111.2, C113.2, C115.2, C117.2, J101.2, J102.7, J102.8, J104.5, R103.2, R104.2, R105.2, R107.2, R108.2, U101.1 (GND), U102.2 (VSS), U102.8 (STBY), U103.1 (GND), U104.2 (GND), U105.8 (VSSA), U105.23 (VSS), U105.35 (VSS), U105.47 (VSS)
unnamed: C110.2, C112.2, C114.2, C116.2, C118.2, U105.1 (VBAT), U105.24 (VDD), U105.36 (VDD), U105.48 (VDD)
unnamed: D101.2 (A), J101.1
unnamed: D102.1 (K), R103.1
unnamed: D103.1 (K), R104.1
unnamed: D104.1 (K), R105.1

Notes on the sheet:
BOOT0: 1 = Bootloader, 0 = 'Run'
https://www.mouser.ca/ProductDetail/Diodes-Incorporated/AZ1084CD-5.0TRG1?qs=5V6w%252Be2aIqY1QaMHWnvTJw%3D%3D
CL = 2 * (Cload - Cstray)
'Light' low-pass filter for analog VDD
Bulk Decoupling
https://www.digikey.ca/en/products/detail/diodes-incorporated/AZ1084CD-3-3TRG1/4470961
GAIN: 100 V/V
max Id = 200 mA
XT60 Female connector
CAN Transceiver
Programming/Debug header for STM
1206

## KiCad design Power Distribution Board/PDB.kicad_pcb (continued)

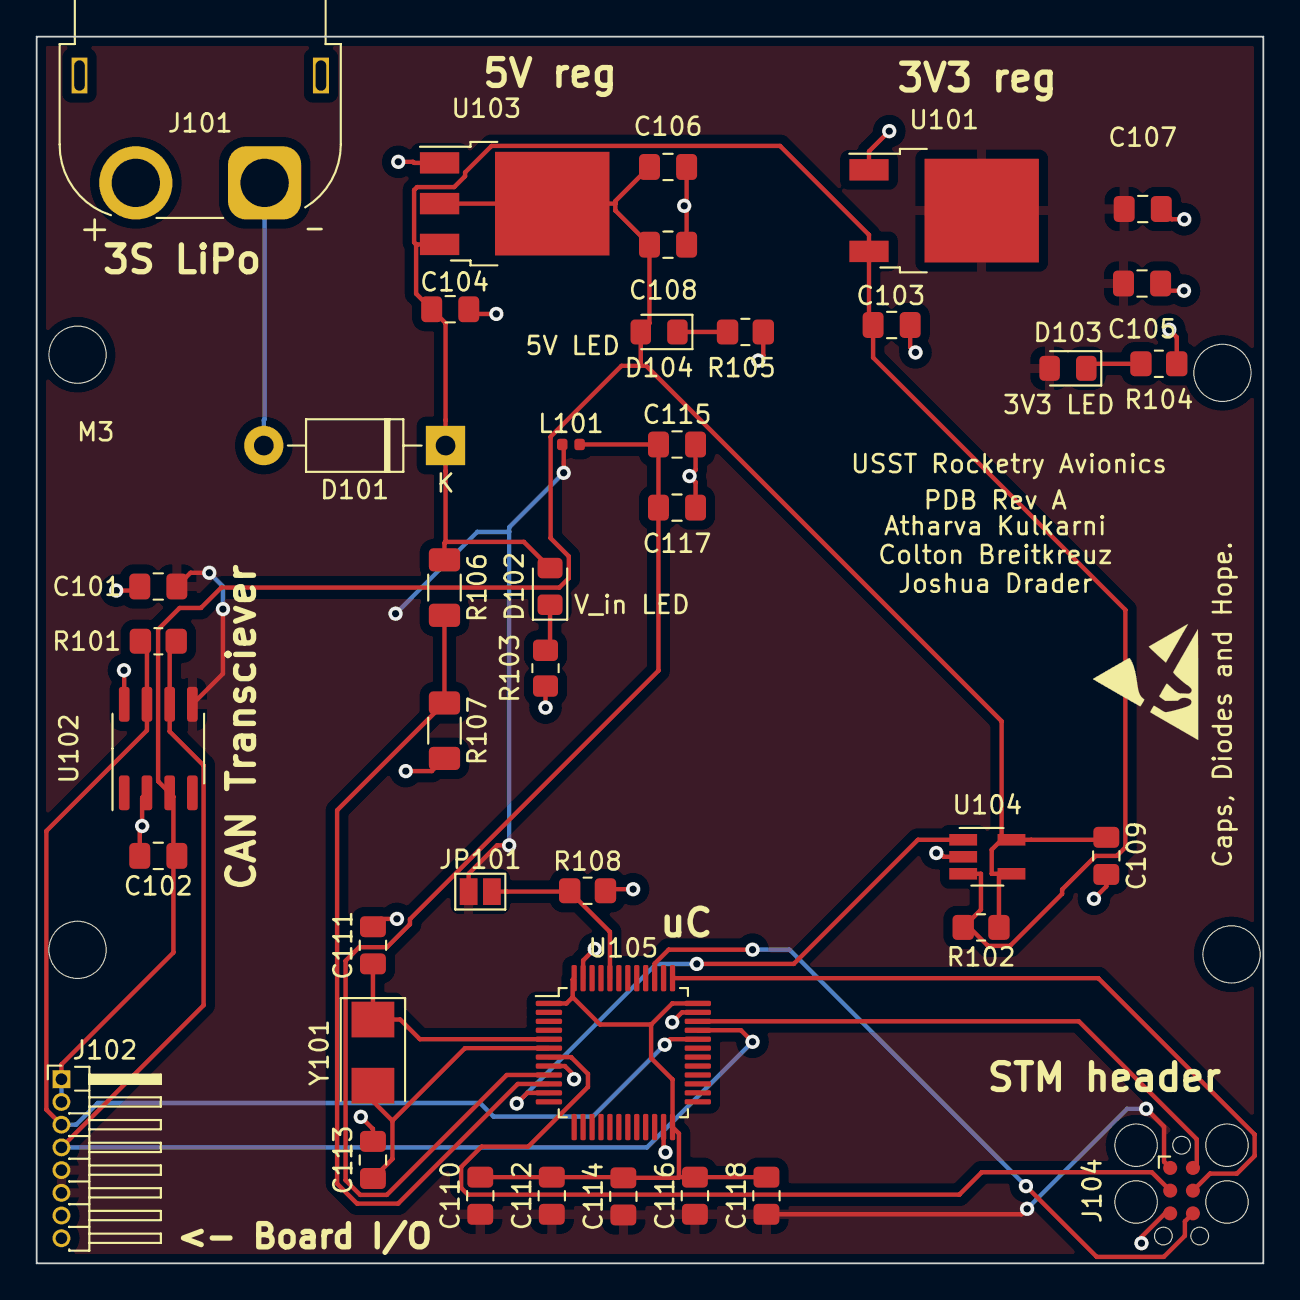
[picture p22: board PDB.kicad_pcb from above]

Board: 2 copper layers, 68.6 x 68.6 mm, 42 parts (0 on the bottom side), 21 nets.

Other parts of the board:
M3: MountingHole_3.2mm_M3

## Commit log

2023-03-26 moved repos here
    [GPS-B_Cu.gbr, GPS-B_Mask.gbr, GPS-B_Paste.gbr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]
2023-03-28 changed file names
    [GPS-B_Cu.gbr, GPS-B_Mask.gbr, GPS-B_Paste.gbr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]
2023-04-02 added gitignore
    [PDB.csv]
2023-04-02 Initial LoRa commit
    [LoRa.kicad_pcb, LoRa.kicad_sch]
2023-04-02 RF initial commit
    [RF.kicad_pcb, RF.kicad_sch]
2023-04-05 RF: initial commit CC1110 and Balun
    [Balun.kicad_sch, RF.kicad_sch, RF_front_end.kicad_sch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]
2023-04-09 Updated GPS Board Schematic, still need to remake board
    [GPS.kicad_sch]
2023-04-15 added external memory
    [Balun.kicad_sch, RF.kicad_sch, RF_front_end.kicad_sch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]
2023-04-15 RF: Push for schematic capture review version 1.0
    [RF.kicad_sch, RF_front_end.kicad_sch, RF_switch.kicad_sch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]
2023-04-15 RF: added pdf
    [memory.kicad_sch]
2023-04-19 added standard connector and some initial layout
    [RF.kicad_pcb, RF.kicad_sch, SUCK.kicad_sch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]
2023-06-25 added flight computer files
    [BMI088.kicad_sch, BMP280.kicad_sch, MCP2515-I-SO.kicad_sch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]
2023-07-24 layout rev 1.0
    [RF.kicad_pcb, RF.kicad_sch, SUCK.kicad_sch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]
2023-07-24 connections ting
    [RF.kicad_pcb, RF.kicad_sch]
2023-08-26 added module templates
    [BMI088.kicad_sch, BMP280.kicad_sch, MCP2562-E-SN.kicad_sch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]
2023-09-02 Updated STM32F405RGT6 template
    [STM32F405RGT6.kicad_sch]
2023-09-03 Added flight comp V2 STM, KX134, BMP280, MCP2562
    [BMP280.kicad_sch, Flight_Computer_V2.kicad_pcb, Flight_Computer_V2.kicad_sch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]
2023-09-04 added more sensors to flight computer v2
    [4-20maSignal_sch.kicad_sch, BMI088.kicad_sch, BMP280.kicad_sch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]
2023-09-04 more flgiht computer v2 updates
    [4-20maSignal_sch.kicad_sch, Flight_Computer_V2.kicad_sch, STM32F405RGT6.kicad_sch]
2023-09-05 finalized schematic, added datasheets, and pdf of schematic
    [4-20maSignal_sch.kicad_sch, BMI088.kicad_sch, BMP280.kicad_sch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]
2023-09-09 updated pcb
    [4-20maSignal_sch.kicad_sch, BMI088.kicad_sch, BMP280.kicad_sch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]
2023-10-14 updated v2 flight computer
    [Flight_Computer_V2.kicad_pcb, STM32F405RGT6.kicad_sch]
2023-10-20 changed new flight computer scl resistors
    [Connector.kicad_sch, Flight_Computer_V2.kicad_sch, MB85RC256VPF-G-JNERE2.kicad_sch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]
